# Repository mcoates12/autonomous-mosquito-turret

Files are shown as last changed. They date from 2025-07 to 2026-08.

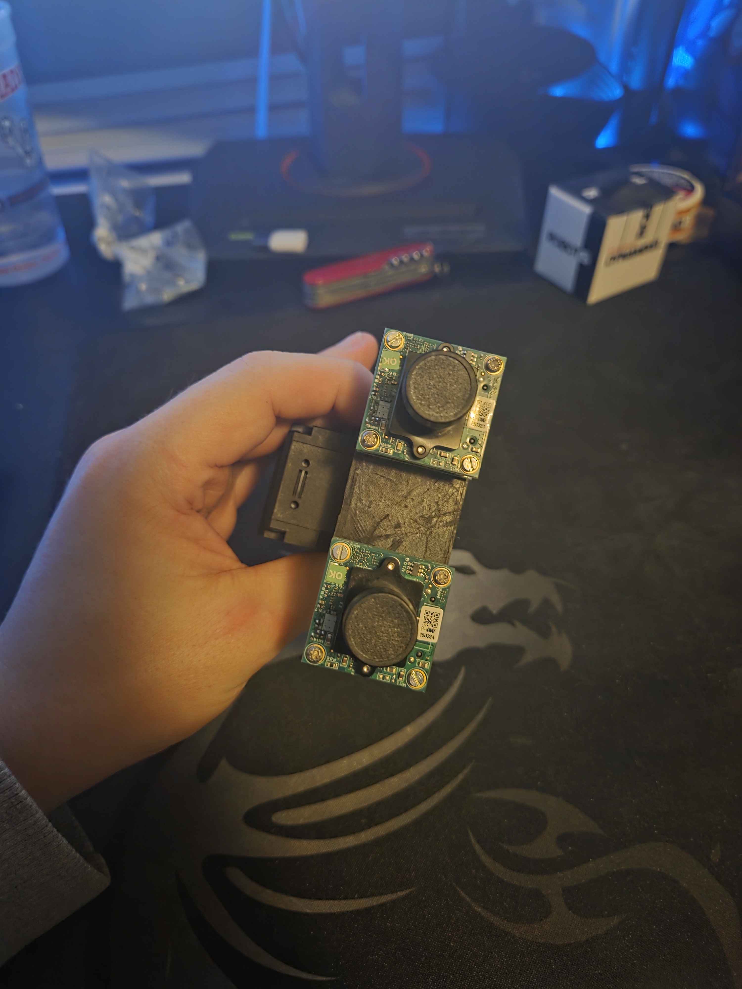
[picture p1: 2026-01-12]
images/turret3.jpg

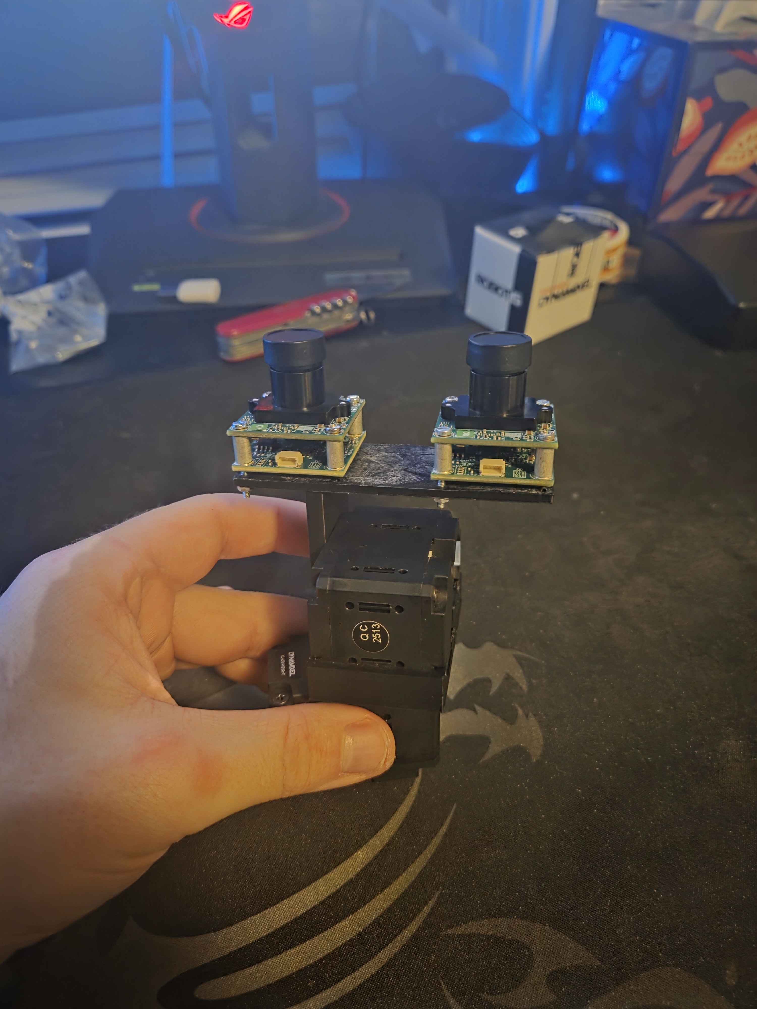
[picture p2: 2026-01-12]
images/turret1.jpg

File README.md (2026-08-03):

# Autonomous Mosquito-Killing Turret

A real-time, dual-camera turret system designed to detect, track, and eliminate mosquitoes using AI-based vision, stereo depth estimation, and precision servo control. Built solo from scratch as a self-funded engineering challenge and proof of capability.

---

## Objective

Create a fully autonomous turret capable of:
- Detecting flying mosquitoes in real-time up to 2 meters away
- Tracking targets using stereo vision and depth estimation
- Driving high-speed Dynamixel servos to follow targets
- Executing a "kill" action (via zap or simulated event)
- Implements real-time mosquito path prediction using a Kalman filter to estimate future positions and improve turret accuracy.

---

## System Overview

| Component | Description |
|---|---|
| Jetson Orin Nano | Real-time inference, image processing, control logic  |
| 2x AR0234 Cameras| Global shutter cameras for synchronized stereo input  |
| 16mm Lenses | Narrow FOV for long-range detection accuracy |
| Dynamixel XL430  | Precision pan/tilt control with speed + torque |
| YOLO | Object detection model trained on mosquito imagery |
| 3D Printed Parts | Custom mounts, housing, and brackets |

---

## Features (WIP)

- [x] Hardware purchased
- [x] Prototype brackets and mounts 3d printed
- [x] Dual-camera vision setup
- [x] Servo communication + movement test
- [x] Depth estimation from stereo input
- [ ] Path prediction via kalman filter
- [ ] Real-time AI inference
- [ ] Final turret housing designed
- [ ] Turret Housing 3d printed
- [ ] Multi-step kill logic (detection + motion confirm + depth range)
- [ ] Fail-safe & safety protocols
- [ ] Audible status beeps for states (idle, tracking, kill-ready)

---

## Project Structure

---

## Browser troubleshooting dashboard

The recommended troubleshooting interface runs on the Jetson without a Linux
desktop or VNC session. Camera capture, detection, and servo control stay on the
Jetson; the PC receives a reduced-rate diagnostic MJPEG preview and sends only
validated parameter changes.

On the Jetson:

```bash
cd ~/Documents/autonomous-mosquito-turret
git pull --ff-only origin main
python3 src/laser_follow_web.py
```

Tracking starts disabled. Keep the Jetson terminal open, and press `Ctrl+C` for
a clean shutdown and torque-off.

When using VS Code Remote SSH, open the **Ports** panel, choose **Forward a
Port**, enter `8080`, then open the forwarded address in the PC browser.

Alternatively, keep this command running in a Windows PowerShell window:

```powershell
ssh -N -L 8080:127.0.0.1:8080 myles@192.168.1.141
```

PowerShell showing no prompt or output means the tunnel is working. Open
<http://127.0.0.1:8080> in the PC browser. The dashboard automatically disables
tracking if its heartbeat disappears for five seconds.

For a trusted private LAN only, the dashboard can be exposed directly with
`python3 src/laser_follow_web.py --bind 0.0.0.0`, then opened at
`http://JETSON_IP:8080`. This mode has no authentication, so the SSH/VS Code
forward is preferred.

The diagnostic stream defaults to 10 FPS at 960 pixels wide and does not set
the camera capture rate. On a heavily loaded Jetson, reduce dashboard overhead
with `--preview-fps 5 --preview-width 640`.

During active tracking, reacquisition remains anchored to the last accepted
target. If the dot is lost, the turret holds instead of switching to a distant
red object. Press **Stop**, place the dot at the new location, and press
**Start** to deliberately clear that identity and perform a fresh full-frame
acquisition. The dashboard's `Reacquire radius` controls the allowed distance.

The outer motion loop uses independent pan and tilt proportional gains plus
filtered derivative damping. Damping is calculated from timestamped target
error, so it does not depend on camera or controller frame rate. It resets on
target loss, stale data, or tracking stop. The starting values are pan/tilt
gain `0.003`, pan damping `0.006`, tilt damping `0.003`, smoothing `35 ms`, and
maximum step `0.60 deg`. Raise damping gradually to reduce single-pass
overshoot; excessive damping can produce twitch or hesitation.

Servo goal commands remain at the selected controller rate (60 Hz by default),
while position/velocity feedback runs at 30 Hz and full health telemetry at
1 Hz. Hardware-error bytes are checked against the XL430's defined `0x3D` bit
mask; impossible reserved-bit values are retried and persistent invalid reads
still trigger the torque-off safety latch.

The runtime prefers the Jetson `nvv4l2camerasrc`/`nvvidconv` VIC conversion
path and automatically falls back to the portable software pipeline if it is
unavailable. In the preview overlay, `FPS` is the processed tracking rate and
`src` is the selected camera's independently measured delivery rate.

> 🔍 [Read the full project backstory → logs/project-intro.md](logs/project-intro.md)

## 👤 Author

**Myles**  
Junior Mechanical Engineering Student  
Self-taught builder | Defense-focused 

Feel free to fork, contribute, or reach out for questions.

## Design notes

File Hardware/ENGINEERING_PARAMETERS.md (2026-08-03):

# Turret Engineering Parameters

Last updated: 2026-08-02

This file records measured and modeled parameters used for controller sizing,
tracking development, and future calibration. Values marked preliminary must be
remeasured after the final lenses, wiring, fasteners, and accessory hardware are
installed.

## Camera system

- Camera count: 2
- Sensor: onsemi AR0234 global shutter
- Capture format: 1920 x 1200, UYVY
- Confirmed capture rate: 60 FPS
- Pixel size: 3 micrometers
- Lens holder: expected M12 x 0.5 S-mount; verify against the exact camera module
  before ordering replacements
- Current focus: manually adjusted by threading each lens in or out
- Final replacement lens focal length: not yet selected
- The README's 16 mm lens entry describes an intended configuration, not a
  verified final optical configuration

The stored camera calibration has approximately 1,105 pixel focal length. With
3 micrometer pixels, this implies that the lenses used for those images were
approximately 3.3 mm focal length. This estimate is approximate because focus,
distortion, and calibration quality affect the fitted intrinsics.

### Known V4L2 controls

- `/dev/video1` identifies Camera 1 (`ar0234 10-0042`) and reports
  1920 x 1200 UYVY capture at 60 FPS
- Exposure modes: full-frame automatic, manual, and ROI automatic
- Absolute exposure range: 1 to 10,000
- Gain range: 1 to 40
- Automatic and fixed white balance are supported
- Low-latency mode is supported
- Current software startup: automatic exposure and automatic white balance,
  gain 1, and low-latency mode enabled
- Manual tuning starts from exposure 100 (10 ms under standard V4L2 units) and
  fixed white balance 4600 when the operator enables those modes
- The GUI caps manual exposure at 160 (16 ms) to avoid silently reducing a
  nominal 60 FPS stream through excessive exposure time

## Stereo calibration

Historical calibration record:

- Captured stereo pairs: 22
- Usable stereo pairs: 21
- Checkerboard: 9 x 6 inner corners
- Measured square size: 18 mm
- Left reprojection RMS: 0.1703 pixels
- Right reprojection RMS: 0.1772 pixels
- Stereo reprojection RMS: 0.5314 pixels
- Reported corrected baseline: 0.0500 m

Important active-file mismatch:

- `src/stereo_calib/stereo_calibration_full.npz` currently embeds a 0.040 m
  square size and a 0.111211 m baseline.
- Scaling that baseline by 18/40 gives 0.050045 m, which agrees with the
  historical corrected result.
- The active file therefore has the old scale and must not be trusted for
  metric depth. It would report distances approximately 2.22 times too large.
- Exposure and brightness changes do not inherently invalidate geometric
  calibration, but lens focus changes, lens replacement, or camera movement do.
- Perform the final stereo calibration only after installing, focusing, and
  mechanically locking the final matched lenses.

## Servos and mechanical limits

- Servo model: Dynamixel XL430-W250
- Protocol: 2.0
- Operating mode: position control
- Serial device: `/dev/ttyUSB0`
- Baud rate: 1,000,000
- Pan servo ID: 1
- Tilt servo ID: 2
- Pan hardware range: 0 to 4095 ticks (approximately 0 to 359.91 degrees)
- Tilt hardware range: 0 to 2190 ticks (approximately 0 to 192.48 degrees)
- Temporary software tilt guard: 708 to 2190 ticks (approximately 62.23 to
  192.48 degrees)
- The controller refuses to arm if startup feedback is outside its effective
  software limits.

Known Dynamixel gain values from Wizard screenshots, for both servos:

- Velocity P Gain: 100
- Position I Gain: 0
- Feedforward 2nd Gain: 0

Still to record:

- Velocity I Gain
- Position D Gain
- Position P Gain
- Feedforward 1st Gain

## Preliminary tilt-axis properties

The modeled tilt payload includes both modeled camera/lens assemblies and the
moving tilt bracket.

- Moving mass: 0.05070 kg
- Weight under standard gravity: approximately 0.497 N
- COG relative to `CS_Tilt`:
  - X: -0.01722 m
  - Y: -0.00020 m
  - Z: 0.03919 m
- Tilt shaft is aligned with the `CS_Tilt` X-axis
- Perpendicular COG radius: 0.03919 m
- Moment of inertia about tilt shaft: 9.0293e-5 kg*m^2
- Maximum static gravity torque: approximately 0.01948 N*m

The tilt model does not yet include external fasteners, wiring/ribbon cables,
accessory hardware, or omitted rotating horn hardware. These values are a
modeled lower bound. Cable forces may contribute more position-dependent torque
than their mass suggests.

## Preliminary pan-axis properties

These properties are based on the current modeled upper assembly.

- Moving mass about pan axis: 0.11850 kg
- COG relative to `CS_Pan` in the upright/startup pose:
  - X along pan shaft: 0.03269 m
  - Y: 0.00168 m
  - Z: -0.00581 m
- Radial COG offset from pan shaft: approximately 0.00605 m
- Pan inertia in upright/startup pose: 6.54e-5 kg*m^2
- Estimated worst-case pan inertia over current tilt range: 1.69e-4 kg*m^2
- Conservative pan inertia for controller sizing: 1.7e-4 kg*m^2

Assuming the pan shaft is vertical, gravity does not create commanded torque
about the pan axis. Pan torque is dominated by angular acceleration, drivetrain
friction, cable resistance, and any base inclination.

## Current preliminary controller parameters

- Control update target: 60 Hz
- Dynamixel Profile Velocity starting value: 200
- Dynamixel Profile Acceleration starting value: 30
- Tracking smoothness is prioritized over the fastest possible acquisition,
  while retaining enough response to follow a moving target
- Red-dot detection is the current test source; the detector/controller seam is
  intentionally model-neutral for a later object detector

Desired maximum physical pan and tilt speeds have not yet been selected.

## Remaining measurements and validation

- Run the committed controller on the Jetson and collect
  `laser_follow_debug.log`.
- Record stationary, slow-sweep, fast-sweep, reversal, and irregular-motion
  tests when lighting permits.
- Establish the physical aim point in image coordinates rather than assuming
  the numerical image center.
- Measure camera/aiming-axis offsets from the pan and tilt axes.
- Record the missing Dynamixel gains.
- Select desired maximum pan and tilt speeds.
- Perform controlled 50, 100, 250, and 500 pixel step-response tests.
- Record acceptable overshoot and settling time, plus observed backlash,
  buzzing, oscillation, and axis coupling.
- Measure end-to-end camera-to-motion latency before tuning prediction or
  feedforward lead.
- Recalculate final mass, COG, and inertia after all hardware and cable routing
  are complete.

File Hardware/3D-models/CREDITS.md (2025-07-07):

# Credits

## Side Mount for XL430 Servo

**Model:** Dynamixel Mounting Plate  
**Author:** Dash Daring ([Printables profile](https://www.printables.com/@DashDaring_227093))  
**License:** [Creative Commons BY-NC 4.0](https://creativecommons.org/licenses/by-nc/4.0/)  
**Source:** [https://www.printables.com/model/924210-dynamixel-mounting-plate/files](https://www.printables.com/model/924210-dynamixel-mounting-plate/files)  
**Notes:** Modified to allow the mount to fit directly onto another servo horn.

---

## Dynamixel XL430-W250-T SolidWorks Files

**Model:** XL430-W250-T  
**Author:** Florian F  
**License:** Not specified on source page  
**Source:** [https://grabcad.com/library/dynamixel-xl430-w250-t-1](https://grabcad.com/library/dynamixel-xl430-w250-t-1)  
**Notes:** No modifications were made. Attribution included out of courtesy.

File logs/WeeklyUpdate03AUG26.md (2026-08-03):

# Project Update — Tracking and Control Overhaul

It has been a while since I seriously worked on this project, but over the last
few days I came back to it and made what is probably the biggest software jump
the turret has had so far.

The goal for this round of work was not to add the mosquito-detection model yet.
I still want to find an existing model trained on mosquitoes if possible instead
of immediately committing to building and labeling an entire dataset myself.
For now, I wanted to get the camera pipeline, red-dot detection, targeting,
servo control, safety behavior, and troubleshooting workflow as polished as I
could. The red laser dot is still acting as a stand-in target so I can work on
the motion system without mixing AI-model problems into controller problems.

At this point, the tracking is honestly close to perfect. There are still a few
small parameters I can min/max, but the turret went from laggy, jittery, and
occasionally locking onto random objects to tracking fast laser movement very
smoothly.

---

## The Original Performance Problem

The biggest problem when I started was rectification. As soon as I loaded the
GUI, the camera pipeline dropped to around **8 FPS**, even though both AR0234
cameras are capable of delivering **1920 × 1200 UYVY at 60 FPS**.

The debug timing made the bottleneck obvious:

- Camera capture: roughly **35–37 ms**
- Full-frame rectification: roughly **80.8 ms**
- Red-dot detection: roughly **18–19 ms**

The software was doing expensive stereo work in the main tracking path whether
it was needed or not. That meant the detector and controller were constantly
working from old frames, which made the entire turret feel delayed.

I reworked the pipeline so that:

- Each camera has a latest-frame capture thread instead of making the tracking
  loop wait on every frame.
- Old frames are dropped instead of building a backlog.
- Red-dot detection runs on the raw tracking-camera image.
- Full stereo rectification and disparity work happen only on scheduled depth
  updates.
- Depth processing runs in a separate worker and consumes only the newest
  request.
- Rectification maps use OpenCV's faster fixed-point representation.
- Preview rendering is demand-driven, so a future headless system does not pay
  for GUI work it is not using.

This removed full-frame rectification from the critical tracking path.

---

## Jetson Camera Acceleration

The next major improvement was the camera conversion pipeline. The Jetson was
spending too much time doing UYVY-to-BGR conversion in software, so I added an
NVIDIA VIC-accelerated GStreamer path using `nvv4l2camerasrc` and `nvvidconv`.
The software still has a portable conversion fallback if the accelerated path
cannot open.

There was an additional caps-negotiation problem that caused GStreamer critical
warnings and fallback behavior. I corrected the pipeline so the caps are fixed
properly before OpenCV receives the frames.

After these changes, the tracking pipeline went from roughly **8 FPS** to around
**55–60 FPS**. The browser preview can intentionally run slower to save network
and encoding overhead, but the actual camera capture, detection, and controller
continue running at full speed on the Jetson.

---

## Camera Exposure and Lighting

One of the early tests looked almost completely black. I originally thought
something was wrong with the camera, but the manual exposure settings were just
far too dark for the room.

The software now starts with:

- Automatic exposure enabled
- Automatic white balance enabled
- Gain set to **1**
- Low-latency camera mode enabled

Manual controls are still available when I need repeatable detector tests. The
starting manual exposure is **100**, which is approximately **10 ms** using the
standard V4L2 units. The GUI caps manual exposure at **160**, or approximately
**16 ms**, so a long exposure cannot silently force a nominal 60 FPS stream to
run slower.

Sunlight was still making the red dot difficult to detect. It turned out that
the laser pointer battery was also weak. Replacing the battery made a huge
difference and gave the detector a much cleaner target.

---

## Headless Browser Dashboard

The Qt GUI is only a troubleshooting tool. The final turret is supposed to run
headless, so I added a browser dashboard that runs directly from the Jetson.

The Jetson now handles:

- Camera capture
- Detection
- Stereo depth work
- Servo control
- Safety logic

My PC only receives a reduced-rate MJPEG troubleshooting preview and sends
validated parameter changes back to the Jetson. I can access it through VS
Code's SSH port forwarding or a normal SSH tunnel, so I no longer need to fight
with VNC, X11 forwarding, black screens, or Qt display errors.

The dashboard also has a heartbeat fail-safe. If the browser connection
disappears for five seconds, tracking is disabled.

No private IP address or network credentials are stored in the repository.

---

## Red-Dot Detector Improvements

The original red detector worked in ideal conditions, but it would either miss
the dot in bright lighting or lock onto things like the brown cardboard box at
the bottom of the camera image.

I added several layers of filtering:

- Brightness threshold
- Saturation threshold
- Minimum and maximum blob area
- Peak-brightness gate
- Local brightness-contrast gate
- Local red-contrast gate
- Hard area gate
- Image-edge exclusion

The detector now preserves tiny laser candidates instead of removing them with
an overly aggressive morphology pass. It also rejects broad reddish or brown
objects that do not have the small, bright, locally red appearance of the laser
dot.

Candidates near the image edge are ignored because partial blobs and bright
objects cut off by the frame were causing false locks.

The current detector values are:

- Brightness threshold: **80**
- Saturation threshold: **35**
- Minimum area: **1 pixel**
- Maximum area: **3000 pixels**
- Peak brightness gate: **140**
- Local contrast gate: **25**
- Local red-contrast gate: **12**
- Image-edge exclusion: **48 pixels**
- Hard area gate: **3000 pixels**

These are troubleshooting values for the red-dot detector, not permanent
mosquito-model parameters.

---

## Target Identity and Reacquisition

Another serious problem was target switching. If the dot moved quickly or
temporarily disappeared, the detector could jump to an unrelated red object and
then keep moving its search anchor toward that false target.

The detector now preserves the last confirmed target identity. During active
tracking, a new candidate must stay within the configured **300-pixel
reacquisition radius** of the last accepted target. Rejected outliers do not get
to move the anchor.

If the dot is lost, the turret holds its position instead of searching the
entire frame and choosing a random red object. Pressing **Stop** and then
**Start** intentionally clears the old identity and allows a fresh full-frame
acquisition.

This logic is detector-neutral, so the same target-observation interface can be
used by a future mosquito model.

---

## Servo Controller Rewrite

I separated servo control from the camera frame loop. The Dynamixel bus now has
its own fixed-rate controller thread that always consumes the newest target
error instead of sending commands whenever a camera frame happens to finish.

The controller now includes:

- Fixed-rate **60 Hz** goal commands
- Latest-target-only behavior
- Stale-target rejection
- Time-scaled movement that does not change with frame rate
- Safe startup without jumping to an old command
- Explicit torque-off behavior
- Dynamixel bus watchdog configuration
- Position, velocity, load, voltage, temperature, and hardware-error telemetry
- Thread-safe shutdown and fault latching

Position and velocity feedback now run at **30 Hz**, while full health telemetry
runs at **1 Hz**. Goal commands remain at 60 Hz. This reduces unnecessary bus
traffic because a servo feedback transaction was taking roughly **12–14 ms**
inside a **16.7 ms** controller period.

The 1 Hz health transaction already includes position and velocity, so the
software reuses that information instead of immediately performing another
feedback read.

---

## Servo Limits and Safety

The software reads the position limits stored in the servos instead of assuming
generic values.

Current limits:

- Pan ID 1: **0–4095 ticks** (approximately 0–359.91°)
- Tilt ID 2 hardware range: **0–2190 ticks** (approximately 0–192.48°)
- Temporary software tilt guard: **708–2190 ticks** (approximately
  62.23–192.48°)

The extra tilt minimum is a conservative mechanical restriction based on the
current assembly. I can change it later after more physical testing. The
controller refuses to arm if the startup feedback is outside the effective safe
range.

Tracking starts disabled, and confirmed controller faults torque the system off
and remain latched until I explicitly re-arm it.

---

## Dynamixel Communication Faults

While testing fast movement, the servo system occasionally shut itself off.
The first problem was an `Incorrect status packet` response during the hardware
status read. I added three bounded attempts with a short delay between them.
A persistent communication problem still shuts down and latches the controller.

Later, the log reported:

```text
pan=0xf3 tilt=0x13
```

Those values looked like hardware faults, but they were impossible XL430 error
bytes. The only valid hardware-error bits combine into mask `0x3D`; bits 1, 6,
and 7 are reserved and must always be zero. Both reported values contained
reserved bits.

The software now validates hardware-error bytes against `0x3D`:

- Impossible reserved-bit values are retried.
- Three persistent invalid values become a latched communication fault.
- Valid nonzero hardware-error bits remain immediately fatal.
- The controller never automatically re-enables torque after a confirmed
  failure.

This keeps the safety behavior while preventing one corrupted telemetry byte
from pretending to be two simultaneous servo failures.

---

## Tracking and Damping

The first tracking controller was essentially proportional-only. It moved
toward the current pixel error, but fast laser movement caused oscillation and
single-pass overshoot.

I first tuned the basic values to:

- Pan gain: **0.003 degrees/pixel**
- Tilt gain: **0.003 degrees/pixel**
- Maximum step: **0.60°** at the 60 Hz reference rate
- Target smoothing: **35 ms**
- Deadband: **25 pixels**
- Profile velocity: **200**
- Profile acceleration: **30**

Reducing the pan gain removed the repeated side-to-side oscillation. Reducing
the smoothing delay and maximum step reduced the remaining overshoot, but a
fast pass could still cross the target once and correct back.

I then added independent filtered derivative damping for both axes:

- Pan damping: **0.006**
- Tilt damping: **0.003**

The damping uses the timestamped rate of change of pixel error. When the error
is closing quickly, it begins braking before the turret crosses the target. It
is filtered to reduce detector noise and resets whenever the target is lost,
becomes stale, or tracking is stopped.

This is not a full traditional PID loop, and I do not currently plan to add an
integral term. The controller already accumulates position commands, and an
additional integral term could create windup. The current proportional plus
derivative behavior is smooth, responsive, and very close to where I want it.

---

## Mechanical Parameters Recorded

I rebuilt the assembly in SolidWorks so I could estimate the moving mass,
center of gravity, and moment of inertia for each axis.

### Tilt axis

- Moving mass: **0.05070 kg**
- Weight: approximately **0.497 N**
- Perpendicular COG radius: **0.03919 m**
- Moment of inertia: **9.0293e-5 kg·m²**
- Maximum estimated gravity torque: approximately **0.01948 N·m**

This model includes the two camera/lens assemblies and moving tilt bracket. It
does not yet include all fasteners, wiring, ribbon cables, laser hardware, or
omitted rotating horn hardware.

### Pan axis

- Moving mass: **0.11850 kg**
- Radial COG offset in the upright pose: approximately **6.05 mm**
- Upright moment of inertia: **6.54e-5 kg·m²**
- Estimated worst-case inertia over the tilt range: **1.69e-4 kg·m²**
- Conservative controller-design value: **1.7e-4 kg·m²**

These values give me a much better starting point for future controller sizing
and acceleration limits than guessing from the servo specifications.

---

## Testing and Code Quality

The tracking code is now split into reusable pieces instead of being one giant
GUI-dependent loop. Camera pipelines, target observations, filtering, depth,
servo control, dashboard validation, and motion math can be tested separately.

The repository currently has **47 passing automated tests** covering areas such
as:

- Camera pipeline selection and fallback
- Frame-rate-independent filtering and motion
- Position conversion and safe limits
- Dashboard input validation and heartbeat behavior
- Stale-target handling
- Target identity and reacquisition radius
- Proportional/derivative damping math
- Servo torque-off and fault latching
- Communication retries
- Hardware-status mask validation
- Decoupled command, feedback, and health rates

This is especially important because the final detector may change from a laser
heuristic to YOLO or another model, but the controller and safety behavior
should not have to be rewritten.

---

## Current Status and Next Steps

The turret currently tracks the laser dot at approximately **55–60 FPS** and
moves smoothly without the repeated oscillation I was seeing before. Fast
movement can still use some very small tuning changes, but I would describe the
current behavior as near perfect for this stage of the project.

My next steps are:

1. Make small pan and tilt damping adjustments and record the final values.
2. Record controlled stationary, slow-sweep, fast-sweep, reversal, and
   irregular-motion tests.
3. Measure overshoot, settling time, end-to-end latency, backlash, and any axis
   coupling instead of judging everything only by eye.
4. Establish the physical aiming point in camera coordinates rather than
   permanently assuming the numerical center of the image.
5. Find and integrate a mosquito-detection model behind the existing
   detector-neutral target interface.
6. Add velocity prediction/feedforward after the measured controller baseline
   is complete. A Kalman filter may eventually provide the state estimate, but
   it is not the feedforward loop by itself.
7. Keep the troubleshooting dashboard for development while moving the final
   system toward fully headless operation.

This round of work was a lot of debugging, but the result finally feels like a
real tracking platform instead of a camera script connected to two servos. The
AI model is still ahead, but the foundation it will plug into is dramatically
better than it was before.

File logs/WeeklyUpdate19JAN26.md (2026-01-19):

## Project Update

I was so excited with the progress I made that I logged off and decided to watch a movie and relax. It’s honestly kind of amazing seeing how far this turret has come already, and I’m even more excited to keep pushing forward.

---

## Camera Calibration Progress

E-con finally emailed me back, and I wrote a short OpenCV script to take photos for camera calibration. In total, **22 photos** were taken, with **21 usable** according to OpenCV.

Initially, I tried using my cell phone, but it has a privacy screen that blurs the image edges at an angle, which made it unusable. Since I don’t have access to a printer or a Sharpie, I switched to using my tablet instead.

The first attempt with the tablet was a no-go due to camera lighting settings. After adjusting exposure and brightness on both the cameras and the tablet, I finally got calibration results that (from what I’ve read) are considered quite good:

OpenCV camera errors
Left reprojection error: 0.1703
Right reprojection error: 0.1772
Stereo reprojection error: 0.5314
Baseline (meters): 0.0500
Baseline (centimeters): 5.00

Originally, I generated the checkerboard online with square sizes of **40 mm × 40 mm**, which resulted in an estimated baseline of ~11 cm. That seemed wrong given how close the cameras actually are.

After some checking, thinking, and double-checking, I realized the tablet was **shrinking the image** to fit its aspect ratio. I measured the squares manually with a ruler and found they were actually **18 mm × 18 mm**. After updating that value in the calibration script, OpenCV correctly calculated the camera baseline.

I also added:
- Image rectification (to keep objects aligned on the same axis)
- Centroid detection

---

## Servo Movement

Next, I started working on servo movement. I wrote a small script using the **Dynamixel SDK** and got basic control working.

Unfortunately, I don’t yet have a proper baseplate for the turret, and it’s pretty top-heavy. It kept falling over, so I improvised:
- Broke off a plastic clothes hanger
- Secured it together with electrical tape
- Taped one of my older pan mounts onto it so the servo could sit inside

Not pretty — but functional for now.

---

## Object Detection & Laser Tracking

Once the servos were responding correctly, I started working on actual object-tracking logic. I created `laser_track.py` and decided to test it using a laser pointer on the wall.

Since I have a cat (and cats love laser pointers), it felt like a perfect test case.

Right now, the script:
- Detects the **hue** of the laser
- Initially only detected the laser within ~6 inches of the camera
- Improved detection range by tuning `v_thresh` and `s_thresh`

Lighting was still somewhat challenging due to sunlight coming through my window, but it worked well enough. Watching the turret move and track the laser for the first time was *incredibly* exciting.

After recording a few videos and posting on Facebook and Instagram, I noticed the movement felt slow. I started tuning motion parameters and landed on:

deg_per_px: 0.006 (pan & tilt)
velocity profile: 200
steps: 3
deadband_px: 10

The turret is now significantly faster, but it feels **jittery** — like it wants to move faster but something is holding it back. I expect most of this will be resolved once I integrate proper **PID control**.

---

## Next Steps

Planned work moving forward:

1. Implement **PID controls**
2. Add **prediction logic** using an **Unscented Kalman Filter**
3. Move into AI vision:
   - **Option A:** Find an existing mosquito-detection model
   - **Option B:** Train my own model

I don’t expect GPU limitations to be an issue — I’m running an **RTX 5090**, so local training should be fine. The bigger challenges will be:
- Finding or building a dataset
- Labeling bounding boxes
- Training the model properly

I also plan to include images of:
- Humans
- Cats
- Dogs
- Other insects

This will allow the model to differentiate targets and enforce safety logic so the turret **does not engage** near people or pets.

Additional planned features:
- Safety protocols
- Laser integration
- Audio cues (beeper tones) for:
  - Scanning
  - Lock-on
  - Firing

---

## Project Status & Reflections

It’s hard to say exactly how far along I am, but I’d estimate I’m around **halfway**, maybe a bit more.

This milestone has been one of the most exciting things I’ve ever experienced. Watching something go from a random idea to a system that can **see**, **track**, and **move** is easily one of the top five most rewarding things I’ve ever done.

There are still hardware challenges ahead — especially with the **CSI camera cables**, which are far too short to allow full turret motion. I’m trying to avoid buying new cameras if possible. I may experiment with:
- Short CSI cables → CSI-to-Ethernet converters → Ethernet → back to CSI

I’ve read that longer CSI runs can introduce lag or signal issues, so this will require experimentation.

---

## Closing

Thanks to everyone who’s been following along. I genuinely can’t stress enough how exciting this project has been for me.

See you all next week 🚀

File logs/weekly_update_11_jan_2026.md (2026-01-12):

# Weekly Update – 11 Jan 2026

Progress is going great! I have finally built the tilt mount correctly. Admittedly, it took three additional iterations before I got it right. Along the way, I learned that M2, M2.5, and M3 screws typically use **Japanese Industrial Standard (JIS)** drivers rather than standard Phillips heads, which has significantly improved assembly.

Earlier this week, I spent a day running around trying to find JIS drivers and other necessary tools. I eventually found a large driver set that included JIS bits, picked up wire cutters, and bought additional screws. I then had to make a few trips back to ACE Hardware to find the correct screw length for the cameras. I ultimately settled on **M2×20 screws** and successfully mounted both cameras.

I downloaded **Dynamixel Wizard 2.0** and set up power distribution through the power hub so the servos were properly powered. Using the Wizard, I configured the servos and set the tilt bounds to **62.23° – 191.78°**, ensuring the mount does not collide with the servo or other parts of the system.

Next, I flashed **JetPack 6.2** onto my Jetson Orin Nano and installed a **2 TB M.2 SSD**. After completing the setup, I attempted to install the camera software from the E‑consystems website. Unfortunately, they only provided **L4T version 36.4.0**, while my system is running **36.4.7**. As a result, I’ve been unable to install the camera drivers, QtCAM, or OpenCV. I emailed E‑consystems yesterday requesting the updated drivers and associated files and am currently waiting for a response.

At the moment, progress is somewhat dependent on E‑consystems, so hopefully they note reply soon. In the meantime, I can begin working on basic servo‑movement logic and decide on an object‑detection model. I’m currently leaning toward **YOLOv11**, but I plan to do more research before making a final decision.

Hope everyone has a great week! I’ll be back next week with another progress update. School starts next week as well, but I’ll be doing my best to maintain momentum and keep pushing this project forward.

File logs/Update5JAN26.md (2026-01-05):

Update (Very Late)

I finally printed the tilt mount for the turret. This took around five reprints, with each print taking roughly 5 hours, before I was able to get the servo horn to fit properly into the holes and sit flush with the mount. 
The main issue was that the holes kept warping, since that section of the mount was being printed vertically.

Yesterday, I went to Micro Center and picked up a variety of wires, switches, and related components so I can properly distribute power and handle sensor logic.

Today, I realized that I overshot the dimensions for the strip that the cameras screw into. At this point, I’m deciding whether to cut that section off or just reprint the part entirely.

Once that’s resolved, I’ll move on to the electrical work, followed by the coding phase to get the system moving. After that, I’ll begin camera calibration, and then continue iterating from there.

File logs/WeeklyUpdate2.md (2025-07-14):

# Weekly Update

It looks like I lied in the last weekly update. I ended up spending the first half of the week relaxing and the last half outdoors hanging out with friends. So unfortunately, no progress has been made so far.

I wanted to at least make the mounting bracket for the tilt servo, which I'm designing in SolidWorks as we speak. I should be finished with this either by tonight or tomorrow. This week will be low in productivity as well due to my upcoming Differential Equations and Thermodynamics exams.

After Thursday, I should start turning on all the equipment and updating everything. Then we’ll move on to actually getting the parts moving.

I also updated the first bracket one more time. I couldn’t fit the M2 screws through the 0.8 mm hole and realized the actual radius for that hole should be around 1 mm instead of 0.8 mm. I also cross-threaded one of the holes in the servo horn (whoops). I thought that a bigger screw I had was actually the same size as the M2 screw, but I found out very quickly that wasn't the case—haha.

Luckily, I have another horn, and for the final product, I’ll be replacing the plastic horn that came with it with the aluminum one I bought separately.

I guess that’s what I get for putting black screws on a black mousepad and trying to see the difference in sizes off of that. **Note to self:** set the screws on a white piece of paper or something that isn’t the exact same color as the screws themselves.

That should be it for this weekly update. Hopefully, next week’s should be a little more exciting.

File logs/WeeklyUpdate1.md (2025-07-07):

# Weekly Project Update – Week 1

This week’s update will be shorter than most. I’m taking two summer classes and had two exams this week, so most of my time this week went into studying, recovering from an illness, and the holiday. Still, I’m happy with the progress I made over the last few days.

I bought a SolidWorks 2025 student license a few months ago, and a buddy of mine let me borrow his Ender-3 Pro printer. I spent most of the Friday, Saturday, and today experimenting with printing and learning how the software and hardware work together.

---

## Mount Design and Modifications

I began by searching for different mounts I could 3D print and prototype with to accelerate my turret design process. Eventually, I stumbled upon a side-mount bracket that I’m currently using/modifying for my own specific use case ([see hardware/3d-models/credits.md for source info](./hardware/3d-models/credits.md)).

I printed off the original bracket and it fit perfectly on my XL430-W250-T servo—such a great match.

I started creating the platform that would attach to my pan servo horn so I connect both the pan and tilt servo by those brackets. I created the `PanMount.SLDPRT` file (in `hardware/3d-models`) using SolidWorks, which was a great learning experience. Rather than keeping an unnecessary part,

I thought: *"Why not just modify the original instead?"*

I imported the actual XL430 SolidWorks file so I could get accurate measurements of the screw holes for the horn and distances between each hole. I ended up modifying the bracket five times.

---

## Iterative Prints and Challenges

The first modification is saved as `dynamixel_mounting_plate_v102.stl`. When I printed it, I noticed the screws wouldn’t fit due to the bracket’s thickness (~5mm). I decided to add indents to the bracket so the screw heads could sit flush and the servo would still be able to fit.

This led to `mountfinal.stl`, which has ~0.8mm diameter holes with indents around 1mm deep. Unfortunately, the screw heads didn’t seat properly. I increased the radius in `mountfinalV2`, but the indents weren’t deep enough and the bracket printed messily.

Eventually, I adjusted the depth to ~3.5mm and the radius to ~2mm, resulting in a clean and well-fitting part: `finalmountV3.stl`. But there was another issue. The middle of the servo horn is where the screw is that attaches the horn to the actual servo and it sits at a 2mm height above where the actual screws are located. Which was something I didn't even think about when modifiying the original bracket.

---

## Slicer Settings and Printing Details

I’m currently printing with:
- Wall thickness: 1 mm  
- Wall line count: 3  
- Top/bottom layers: 6  
- Infill: 50%  
- Ironing: Enabled (top only)  
- Ironing flow: 20%  
- Print temp: 210°C (PLA+)  
- Speed: 30 mm/s depending on pass  
- Layer height: 0.2 mm  
- Supports: None  
- Slicer: Ultimaker Cura  

---

## Bracket Update and Next Steps

To avoid modifying the mount further and waiting another 3 hours for it to print, I looked around at the few hardware stores that are open on a Sunday to see if there was any longer m2.5 screws I could buy. Unfortunately, none of the nearby hardware stores that were open carried M2.5 screws, 

so I designed `finalmountV4.stl`, which uses a 2mm indent to better accommodate the raised screw head in the center of the horn.

so I’m waiting another 3 hours for this thing to finish printing.

This version allows the bracket and horn to sit flush while also providing holes for both the bracket and servo screws.

Next, I’m planning to create a **C-style tilt mount** for the second servo, ensuring enough spacing and proper alignment with the pan bracket. This should allow for synchronized movement.

---

## Looking Ahead

Next week, I’ll be:
- Finishing the bracket for the **tilt servo**
- Testing **servo movement**
- Installing cameras
- Starting work on **YOLOv8 model training**
- Learning **OpenCV** and depth estimation with stereo vision
- Beginning to write modular **Python code** for servo/camera integration

This week’s quote, as I begin this journey:

> *"A journey of a thousand miles begins with a single step."* — Lao Tzu

---

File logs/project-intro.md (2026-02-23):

# Project Log 1 – Autonomous Mosquito-Killing Turret

## Why I’m Doing This

By the end of my sophomore year in the BSME program, I wanted to start getting experience. Summer internships were off the table due to enrollment in summer classes, so I applied to the on-campus research program.

After months of emails, reminder follow-ups, and camping outside professors’ offices — I finally got the interview.

It lasted about an hour. Then they told me I wasn’t getting the position due to a lack of experience.

To get this experience I decided to build a self-funded, AI-powered turret that tracks and eliminates mosquitoes in real time.

My goal Isn’t just to kill bugs — it is to prove that I can design, build, and document a complete system from scratch. One that combines mechanical design, computer vision, embedded hardware, and AI.

---

## Final Words

Thank you to whoever stumbles across this and decides to read and follow along as I finish the project. I'm very open to critiques or general advice from more experienced folks. I'm new to GitHub and still learning the ropes.

If this repo starts seeing traffic, maybe I’ll toss in an email.  
Again, thanks for reading.

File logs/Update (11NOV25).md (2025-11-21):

## Project Status Update

Hey everyone!

I just wanted to let you all know that the project is **still actively ongoing**.

Between the end of the summer semester and the start of this one, things have been extremely busy. A lot of my time has been taken up by **schoolwork** and **searching for summer internships**, which slowed down development more than I anticipated.

I’m planning to resume work on the project **around finals**, once my schedule finally opens up again.

Thank you all so much for your patience — I’m excited to get back into this soon!

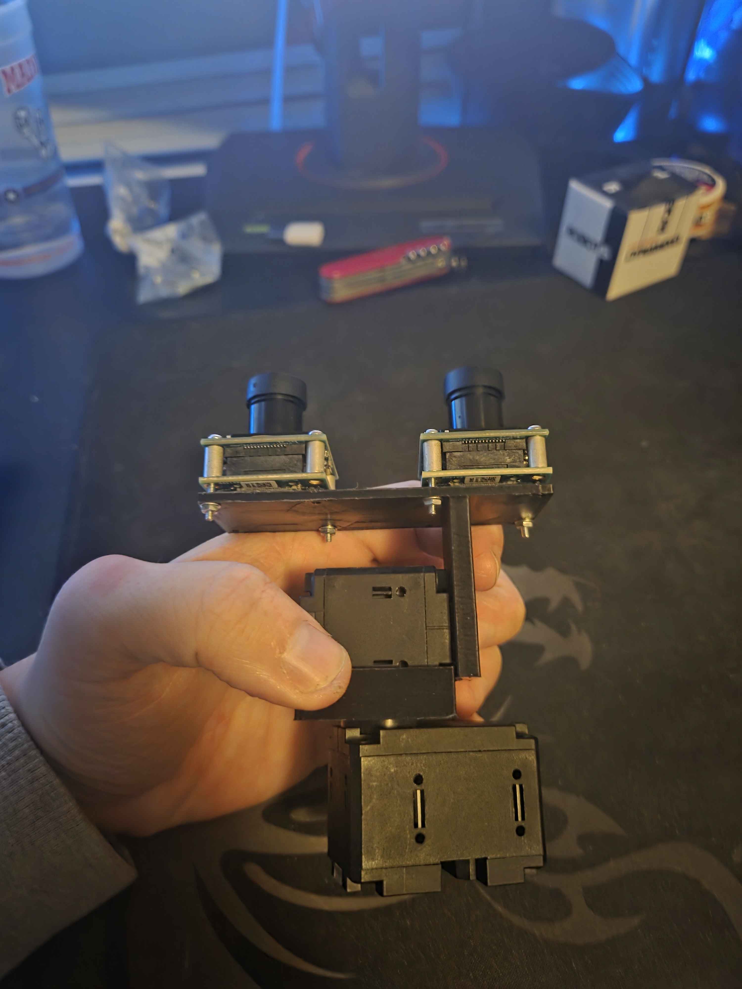
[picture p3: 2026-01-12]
images/turret2.jpg

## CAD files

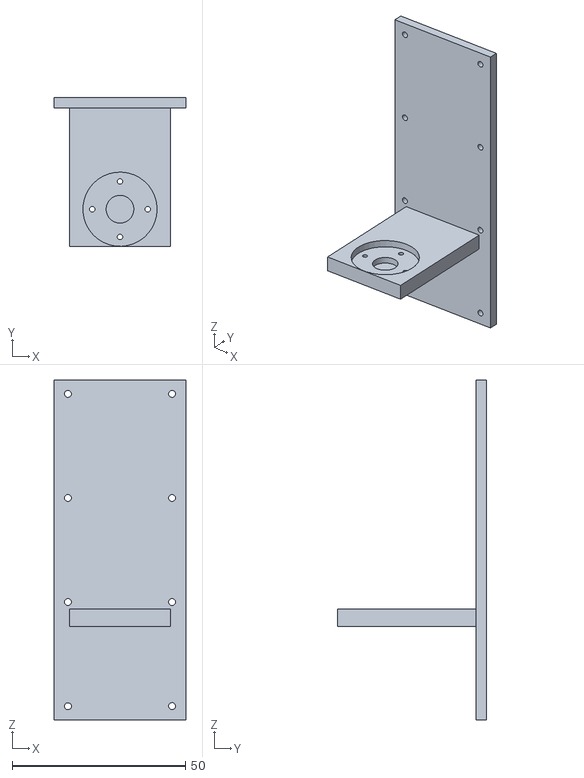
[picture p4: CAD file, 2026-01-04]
Hardware/3D-models/tilt mount V4.STL
38.0 x 43.0 x 98.0

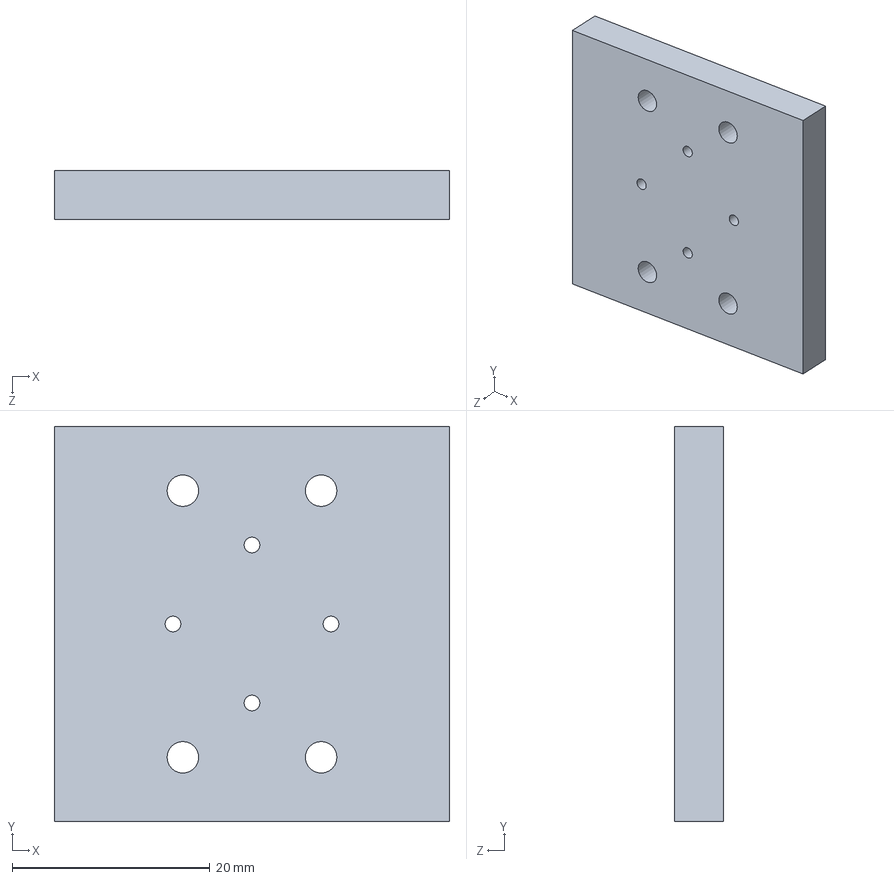
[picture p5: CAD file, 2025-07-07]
Hardware/3D-models/PanMount.SLDPRT
40.0 x 40.0 x 5.00 mm

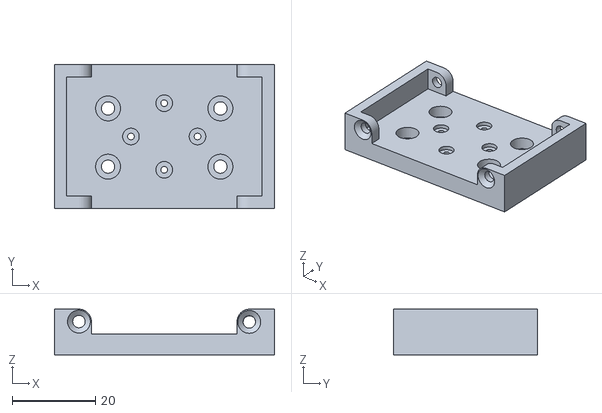
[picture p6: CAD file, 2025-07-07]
Hardware/3D-models/mountfinalV2.STL
52.9 x 34.5 x 11.0

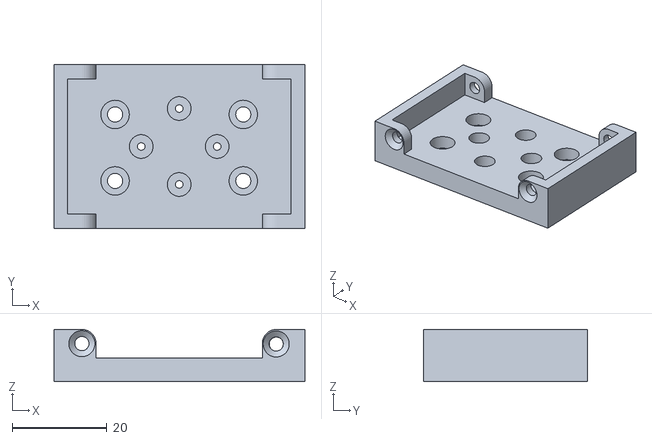
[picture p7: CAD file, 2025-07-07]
Hardware/3D-models/finalmountV4.STL
52.9 x 34.5 x 11.0

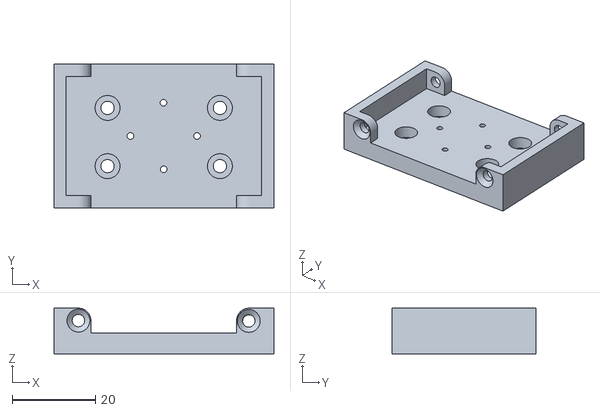
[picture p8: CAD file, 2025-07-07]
Hardware/3D-models/dynamixel_mounting_plate v102.STL
52.9 x 34.5 x 11.0

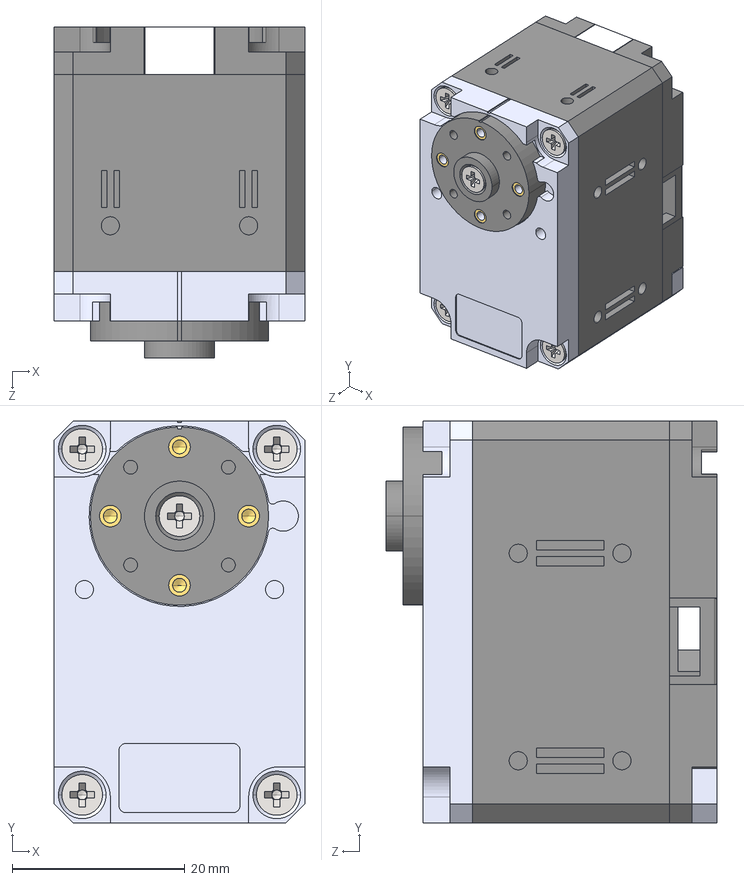
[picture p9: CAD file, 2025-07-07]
Hardware/3D-models/XL430_W250_T.STEP
29.0 x 46.5 x 38.3 mm
Part1^XL430_W250_T
Part2^XL430_W250_T
Part3^XL430_W250_T
Part4^XL430_W250_T
countersunk flat head cross recess screw_din_DIN EN ISO 7046-1 - M2.5 x 10 - Z - 10N x 9
Part5^XL430_W250_T
Part6^XL430_W250_T

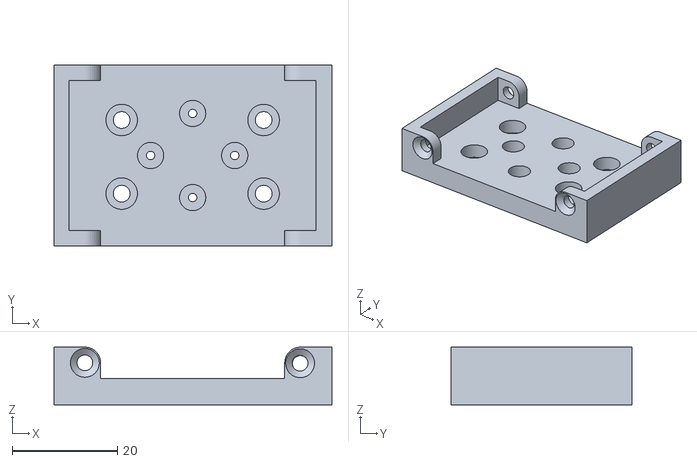
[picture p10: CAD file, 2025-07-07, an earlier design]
Hardware/3D-models/finalmountV3.STL
52.9 x 34.5 x 11.0

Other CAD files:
Hardware/3D-models/mountfinal.STL
Hardware/3D-models/dynamixel_mounting_plate v101.SLDPRT
Hardware/3D-models/tilt mountV1.STL
Hardware/3D-models/tilt mount V3.STL
Hardware/3D-models/tilt mount V2.STL

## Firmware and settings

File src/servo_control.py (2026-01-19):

#!/usr/bin/env python3
"""
Dynamixel XL430 (Protocol 2.0) pan/tilt control via U2D2 (TTL).

Features:
- Soft limits (tilt bounds prefilled)
- Degrees -> ticks conversion (0-360 deg => 0-4095)
- Torque enable/disable
- Operating mode set to Position Control
- Profile velocity control
- Commands: center, goto, step, sweep, status

Wiring:
- U2D2 USB to Jetson
- U2D2 TTL to Dynamixel chain + external power to servos (NOT from USB)

Author: ChatGPT
"""

import argparse
import math
import signal
import sys
import time
from dataclasses import dataclass

from dynamixel_sdk import PortHandler, PacketHandler, GroupSyncWrite, GroupSyncRead  # type: ignore

# -----------------------------
# XL430 Control Table (Protocol 2.0)
# -----------------------------
ADDR_OPERATING_MODE   = 11   # 1 byte
ADDR_TORQUE_ENABLE    = 64   # 1 byte
ADDR_PROFILE_VELOCITY = 112  # 4 bytes (profile velocity, used in position mode)
ADDR_GOAL_POSITION    = 116  # 4 bytes
ADDR_PRESENT_POSITION = 132  # 4 bytes

LEN_OPERATING_MODE   = 1
LEN_TORQUE_ENABLE    = 1
LEN_PROFILE_VELOCITY = 4
LEN_GOAL_POSITION    = 4
LEN_PRESENT_POSITION = 4

OPERATING_MODE_POSITION = 3  # Position Control Mode

TORQUE_ON  = 1
TORQUE_OFF = 0

# XL430 resolution: 0..4095 ticks for 0..360 degrees
TICKS_PER_REV = 4096.0
DEG_PER_TICK = 360.0 / TICKS_PER_REV


# -----------------------------
# Configuration (edit these)
# -----------------------------
@dataclass
class ServoConfig:
    servo_id: int
    name: str

    # Soft limits in DEGREES (logical, after applying invert/offset)
    min_deg: float
    max_deg: float

    # Home position in degrees (logical)
    home_deg: float

    # Optional: invert direction if your servo rotates opposite your desired sign
    invert: bool = False

    # Optional: offset in degrees (logical 0deg maps to physical position)
    # Example: if "0 deg" in your logic corresponds to servo sitting at physical 180 deg, set offset_deg=180
    offset_deg: float = 0.0


@dataclass
class TurretConfig:
    port: str = "/dev/ttyUSB0"
    baud: int = 1000000  # common default; change if you set different in Dynamixel Wizard
    protocol: float = 2.0

    # Limit rate of change to prevent whipping around
    max_step_deg_per_cmd: float = 15.0

    # Default profile velocity (0 = max, but don't do that). This value is in Dynamixel units.
    # Typical safe starting points: 50–200. Tune later.
    profile_velocity: int = 120

    # Servos
    pan: ServoConfig = ServoConfig(
        servo_id=1,
        name="pan",
        min_deg=0.0,
        max_deg=360.0,
        home_deg=180.0,
        invert=False,
        offset_deg=0.0,
    )

    tilt: ServoConfig = ServoConfig(
        servo_id=2,
        name="tilt",
        # Using YOUR safe tilt bounds:
        min_deg=62.23,
        max_deg=191.78,
        home_deg=120.0,
        invert=False,
        offset_deg=0.0,
    )


# -----------------------------
# Helpers
# -----------------------------
def clamp(x: float, lo: float, hi: float) -> float:
    return max(lo, min(hi, x))


def wrap_deg_0_360(deg: float) -> float:
    # keep in [0, 360)
    d = deg % 360.0
    if d < 0:
        d += 360.0
    return d


def int_to_little_endian_bytes(value: int, length: int) -> bytes:
    return int(value).to_bytes(length, byteorder="little", signed=False)


# -----------------------------
# Dynamixel Controller
# -----------------------------
class DynamixelTurret:
    def __init__(self, cfg: TurretConfig):
        self.cfg = cfg
        self.port_handler = PortHandler(cfg.port)
        self.packet_handler = PacketHandler(cfg.protocol)

        self.sync_write_goal = GroupSyncWrite(
            self.port_handler, self.packet_handler, ADDR_GOAL_POSITION, LEN_GOAL_POSITION
        )
        self.sync_read_present = GroupSyncRead(
            self.port_handler, self.packet_handler, ADDR_PRESENT_POSITION, LEN_PRESENT_POSITION
        )

        self._torque_enabled = False
        self._last_cmd_deg = {
            cfg.pan.name: None,
            cfg.tilt.name: None,
        }

    def open(self) -> None:
        if not self.port_handler.openPort():
            raise RuntimeError(f"Failed to open port {self.cfg.port}")
        if not self.port_handler.setBaudRate(self.cfg.baud):
            raise RuntimeError(f"Failed to set baudrate {self.cfg.baud} on {self.cfg.port}")

        # Register servos for sync read
        for s in (self.cfg.pan, self.cfg.tilt):
            ok = self.sync_read_present.addParam(s.servo_id)
            if not ok:
                raise RuntimeError(f"Failed to add servo {s.servo_id} to sync read")

    def close(self) -> None:
        try:
            self.torque_off_all()
        except Exception:
            pass
        try:
            self.port_handler.closePort()
        except Exception:
            pass

    # ---------- Low-level read/write ----------
    def write1(self, servo_id: int, addr: int, value: int) -> None:
        dxl_comm_result, dxl_error = self.packet_handler.write1ByteTxRx(
            self.port_handler, servo_id, addr, value
        )
        self._check_comm(servo_id, dxl_comm_result, dxl_error, f"write1 addr={addr} val={value}")

    def write4(self, servo_id: int, addr: int, value: int) -> None:
        dxl_comm_result, dxl_error = self.packet_handler.write4ByteTxRx(
            self.port_handler, servo_id, addr, value
        )
        self._check_comm(servo_id, dxl_comm_result, dxl_error, f"write4 addr={addr} val={value}")

    def read4(self, servo_id: int, addr: int) -> int:
        value, dxl_comm_result, dxl_error = self.packet_handler.read4ByteTxRx(
            self.port_handler, servo_id, addr
        )
        self._check_comm(servo_id, dxl_comm_result, dxl_error, f"read4 addr={addr}")
        return int(value)

    def _check_comm(self, servo_id: int, comm_result: int, dxl_error: int, what: str) -> None:
        if comm_result != 0:
            msg = self.packet_handler.getTxRxResult(comm_result)
            raise RuntimeError(f"[ID:{servo_id}] {what} COMM FAIL: {msg}")
        if dxl_error != 0:
            msg = self.packet_handler.getRxPacketError(dxl_error)
            raise RuntimeError(f"[ID:{servo_id}] {what} DXL ERROR: {msg}")

    # ---------- Setup ----------
    def ping(self) -> None:
        for s in (self.cfg.pan, self.cfg.tilt):
            model, comm, err = self.packet_handler.ping(self.port_handler, s.servo_id)
            self._check_comm(s.servo_id, comm, err, "ping")
            print(f"[OK] {s.name} ID={s.servo_id} model_number={model}")

    def set_position_mode_all(self) -> None:
        # Must disable torque to change operating mode
        self.torque_off_all()
        for s in (self.cfg.pan, self.cfg.tilt):
            self.write1(s.servo_id, ADDR_OPERATING_MODE, OPERATING_MODE_POSITION)
        print("[OK] Operating mode set to POSITION for both servos")

    def set_profile_velocity_all(self, profile_vel: int) -> None:
        # profile velocity can be written with torque on/off; safer with torque off initially
        for s in (self.cfg.pan, self.cfg.tilt):
            self.write4(s.servo_id, ADDR_PROFILE_VELOCITY, int(profile_vel))
        print(f"[OK] Profile velocity set to {profile_vel} (both)")

    def torque_on_all(self) -> None:
        for s in (self.cfg.pan, self.cfg.tilt):
            self.write1(s.servo_id, ADDR_TORQUE_ENABLE, TORQUE_ON)
        self._torque_enabled = True
        print("[OK] Torque ON (both)")

    def torque_off_all(self) -> None:
        for s in (self.cfg.pan, self.cfg.tilt):
            try:
                self.write1(s.servo_id, ADDR_TORQUE_ENABLE, TORQUE_OFF)
            except Exception:
                # if one servo isn't reachable, don't block shutdown
                pass
        self._torque_enabled = False
        print("[OK] Torque OFF (both)")

    # ---------- Conversions ----------
    def deg_to_ticks(self, servo: ServoConfig, deg_logical: float) -> int:
        # apply clamp in logical space first
        deg_logical = clamp(deg_logical, servo.min_deg, servo.max_deg)

        # apply rate limit (per-servo)
        last = self._last_cmd_deg.get(servo.name)
        if last is not None:
            max_step = self.cfg.max_step_deg_per_cmd
            deg_logical = clamp(deg_logical, last - max_step, last + max_step)

        # apply invert + offset mapping to physical deg (0..360 domain)
        d = deg_logical
        if servo.invert:
            # invert around 0 in logical space; you can change this behavior later if needed
            d = -d
        d = d + servo.offset_deg
        d = wrap_deg_0_360(d)

        ticks = int(round(d / DEG_PER_TICK)) % int(TICKS_PER_REV)
        self._last_cmd_deg[servo.name] = deg_logical
        return ticks

    def ticks_to_deg_physical(self, ticks: int) -> float:
        ticks = ticks % int(TICKS_PER_REV)
        return ticks * DEG_PER_TICK

    # ---------- Motion Commands ----------
    def set_pan_tilt_deg(self, pan_deg: float, tilt_deg: float) -> None:
        pan_ticks = self.deg_to_ticks(self.cfg.pan, pan_deg)
        tilt_ticks = self.deg_to_ticks(self.cfg.tilt, tilt_deg)

        # Build sync write packet
        self.sync_write_goal.clearParam()
        ok1 = self.sync_write_goal.addParam(self.cfg.pan.servo_id, int_to_little_endian_bytes(pan_ticks, 4))
        ok2 = self.sync_write_goal.addParam(self.cfg.tilt.servo_id, int_to_little_endian_bytes(tilt_ticks, 4))
        if not (ok1 and ok2):
            raise RuntimeError("Failed to add params to sync write")

        dxl_comm_result = self.sync_write_goal.txPacket()
        if dxl_comm_result != 0:
            msg = self.packet_handler.getTxRxResult(dxl_comm_result)
            raise RuntimeError(f"sync_write_goal COMM FAIL: {msg}")

    def center(self) -> None:
        self.set_pan_tilt_deg(self.cfg.pan.home_deg, self.cfg.tilt.home_deg)

    def read_present_positions(self) -> dict:
        dxl_comm_result = self.sync_read_present.txRxPacket()
        if dxl_comm_result != 0:
            msg = self.packet_handler.getTxRxResult(dxl_comm_result)
            raise RuntimeError(f"sync_read_present COMM FAIL: {msg}")

        out = {}
        for s in (self.cfg.pan, self.cfg.tilt):
            if not self.sync_read_present.isAvailable(s.servo_id, ADDR_PRESENT_POSITION, LEN_PRESENT_POSITION):
                raise RuntimeError(f"Present position not available for servo {s.servo_id}")
            pos = self.sync_read_present.getData(s.servo_id, ADDR_PRESENT_POSITION, LEN_PRESENT_POSITION)
            out[s.name] = int(pos)
        return out


# -----------------------------
# CLI routines
# -----------------------------
def cmd_status(ctrl: DynamixelTurret) -> None:
    pos = ctrl.read_present_positions()
    pan_deg = ctrl.ticks_to_deg_physical(pos["pan"])
    tilt_deg = ctrl.ticks_to_deg_physical(pos["tilt"])
    print(f"PAN:  ticks={pos['pan']:4d}  physical_deg={pan_deg:7.2f}")
    print(f"TILT: ticks={pos['tilt']:4d}  physical_deg={tilt_deg:7.2f}")


def cmd_goto(ctrl: DynamixelTurret, pan: float, tilt: float, settle: float) -> None:
    ctrl.set_pan_tilt_deg(pan, tilt)
    time.sleep(settle)
    cmd_status(ctrl)


def cmd_step(ctrl: DynamixelTurret, axis: str, step_deg: float, n: int, settle: float) -> None:
    # Step around home
    pan = ctrl.cfg.pan.home_deg
    tilt = ctrl.cfg.tilt.home_deg

    for i in range(n):
        sign = 1 if (i % 2 == 0) else -1
        if axis == "pan":
            cmd_goto(ctrl, pan + sign * step_deg, tilt, settle)
        else:
            cmd_goto(ctrl, pan, tilt + sign * step_deg, settle)


def cmd_sweep(ctrl: DynamixelTurret, axis: str, step_deg: float, settle: float) -> None:
    if axis == "pan":
        s = ctrl.cfg.pan
        fixed = ctrl.cfg.tilt.home_deg
        d = s.min_deg
        while d <= s.max_deg + 1e-6:
            ctrl.set_pan_tilt_deg(d, fixed)
            time.sleep(settle)
            d += step_deg
    else:
        s = ctrl.cfg.tilt
        fixed = ctrl.cfg.pan.home_deg
        d = s.min_deg
        while d <= s.max_deg + 1e-6:
            ctrl.set_pan_tilt_deg(fixed, d)
            time.sleep(settle)
            d += step_deg
    cmd_status(ctrl)


def build_argparser() -> argparse.ArgumentParser:
    p = argparse.ArgumentParser(description="Dynamixel XL430 pan/tilt controller (U2D2 TTL).")
    p.add_argument("--port", default=TurretConfig.port, help="Serial port (e.g., /dev/ttyUSB0)")
    p.add_argument("--baud", type=int, default=TurretConfig.baud, help="Baudrate (e.g., 57600, 1000000)")
    p.add_argument("--pan_id", type=int, default=TurretConfig.pan.servo_id, help="Pan servo ID")
    p.add_argument("--tilt_id", type=int, default=TurretConfig.tilt.servo_id, help="Tilt servo ID")
    p.add_argument("--profile_velocity", type=int, default=TurretConfig.profile_velocity, help="Profile velocity (both)")
    p.add_argument("--max_step", type=float, default=TurretConfig.max_step_deg_per_cmd, help="Max deg change per command")

    sub = p.add_subparsers(dest="cmd", required=True)

    sub.add_parser("ping", help="Ping both servos and print model numbers")
    sub.add_parser("center", help="Move to home positions")
    sub.add_parser("status", help="Read present positions and print")

    g = sub.add_parser("goto", help="Move to pan/tilt degrees (logical)")
    g.add_argument("--pan", type=float, required=True)
    g.add_argument("--tilt", type=float, required=True)
    g.add_argument("--settle", type=float, default=0.5)

    st = sub.add_parser("step", help="Step test around home on one axis")
    st.add_argument("--axis", choices=["pan", "tilt"], required=True)
    st.add_argument("--step_deg", type=float, default=5.0)
    st.add_argument("--n", type=int, default=6)
    st.add_argument("--settle", type=float, default=0.5)

    sw = sub.add_parser("sweep", help="Sweep one axis through its soft limits")
    sw.add_argument("--axis", choices=["pan", "tilt"], required=True)
    sw.add_argument("--step_deg", type=float, default=5.0)
    sw.add_argument("--settle", type=float, default=0.4)

    return p


def main() -> int:
    args = build_argparser().parse_args()

    cfg = TurretConfig()
    cfg.port = args.port
    cfg.baud = args.baud
    cfg.profile_velocity = args.profile_velocity
    cfg.max_step_deg_per_cmd = args.max_step

    cfg.pan.servo_id = args.pan_id
    cfg.tilt.servo_id = args.tilt_id

    ctrl = DynamixelTurret(cfg)

    def _sigint_handler(sig, frame):
        print("\n[CTRL+C] Disabling torque and exiting...")
        try:
            ctrl.torque_off_all()
        finally:
            try:
                ctrl.port_handler.closePort()
            except Exception:
                pass
        sys.exit(130)

    signal.signal(signal.SIGINT, _sigint_handler)

    ctrl.open()

    # Basic setup
    ctrl.ping()
    ctrl.set_position_mode_all()
    ctrl.set_profile_velocity_all(cfg.profile_velocity)
    ctrl.torque_on_all()

    if args.cmd == "ping":
        pass
    elif args.cmd == "center":
        ctrl.center()
        time.sleep(0.7)
        cmd_status(ctrl)
    elif args.cmd == "status":
        cmd_status(ctrl)
    elif args.cmd == "goto":
        cmd_goto(ctrl, args.pan, args.tilt, args.settle)
    elif args.cmd == "step":
        cmd_step(ctrl, args.axis, args.step_deg, args.n, args.settle)
    elif args.cmd == "sweep":
        cmd_sweep(ctrl, args.axis, args.step_deg, args.settle)
    else:
        raise RuntimeError("Unknown command")

    ctrl.torque_off_all()
    ctrl.port_handler.closePort()
    return 0


if __name__ == "__main__":
    raise SystemExit(main())

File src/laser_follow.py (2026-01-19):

#!/usr/bin/env python3
"""
Laser follow (red dot) -> Dynamixel pan/tilt

Requires:
  pip install opencv-python dynamixel-sdk numpy

Run example:
  python3 laser_follow.py --port /dev/ttyUSB0 --baud 1000000 --cam 0 --width 1920 --height 1200 --v_thresh 80 --s_thresh 60 --deadband_px 10 --lost_frames_hold 1 --max_step_deg 3.0 --pan_dir -1

Controls:
  q / ESC  : quit (torque off)
"""

import argparse
import signal
import sys
import time
from dataclasses import dataclass

import cv2
import numpy as np
from dynamixel_sdk import PortHandler, PacketHandler, GroupSyncWrite, GroupSyncRead  # type: ignore


# -----------------------------
# Dynamixel XL430 Control Table (Protocol 2.0)
# -----------------------------
ADDR_OPERATING_MODE   = 11
ADDR_TORQUE_ENABLE    = 64
ADDR_PROFILE_VELOCITY = 112
ADDR_GOAL_POSITION    = 116
ADDR_PRESENT_POSITION = 132

LEN_GOAL_POSITION     = 4
LEN_PRESENT_POSITION  = 4

OPERATING_MODE_POSITION = 3
TORQUE_ON, TORQUE_OFF = 1, 0

TICKS_PER_REV = 4096.0
DEG_PER_TICK = 360.0 / TICKS_PER_REV


# -----------------------------
# Config
# -----------------------------
@dataclass
class ServoConfig:
    servo_id: int
    name: str
    min_deg: float
    max_deg: float
    home_deg: float
    invert: bool = False
    offset_deg: float = 0.0


@dataclass
class TurretConfig:
    port: str = "/dev/ttyUSB0"
    baud: int = 1000000
    protocol: float = 2.0
    profile_velocity: int = 200

    # Safety: how far a single update is allowed to change angle
    max_step_deg_per_update: float = 2.0

    pan: ServoConfig = ServoConfig(
        servo_id=1, name="pan",
        min_deg=0.0, max_deg=360.0,
        home_deg=180.0,
        invert=False, offset_deg=0.0
    )
    tilt: ServoConfig = ServoConfig(
        servo_id=2, name="tilt",
        min_deg=62.23, max_deg=191.78,
        home_deg=120.0,
        invert=False, offset_deg=0.0
    )


def clamp(x: float, lo: float, hi: float) -> float:
    return max(lo, min(hi, x))


def wrap_deg_0_360(deg: float) -> float:
    d = deg % 360.0
    if d < 0:
        d += 360.0
    return d


def int_to_le_bytes(value: int, length: int) -> bytes:
    return int(value).to_bytes(length, byteorder="little", signed=False)


# -----------------------------
# Red laser detection (HSV)
# -----------------------------
def find_laser_centroid_red(frame_bgr,
                            v_thresh=80,
                            s_thresh=40,
                            min_area=1,
                            max_area=2000):
    """
    Red-laser dot detection:
    - HSV threshold for red (two hue ranges)
    - Allows low saturation (important at distance on walls)
    """
    hsv = cv2.cvtColor(frame_bgr, cv2.COLOR_BGR2HSV)
    h, s, v = cv2.split(hsv)

    lower1 = np.array([0,   s_thresh, v_thresh], dtype=np.uint8)
    upper1 = np.array([10,  255,      255],      dtype=np.uint8)
    lower2 = np.array([170, s_thresh, v_thresh], dtype=np.uint8)
    upper2 = np.array([179, 255,      255],      dtype=np.uint8)

    mask = cv2.bitwise_or(cv2.inRange(hsv, lower1, upper1),
                          cv2.inRange(hsv, lower2, upper2))

    kernel = np.ones((3, 3), np.uint8)
    mask = cv2.morphologyEx(mask, cv2.MORPH_OPEN, kernel, iterations=1)
    mask = cv2.dilate(mask, kernel, iterations=2)

    contours, _ = cv2.findContours(mask, cv2.RETR_EXTERNAL, cv2.CHAIN_APPROX_SIMPLE)
    if not contours:
        return None, mask

    best = None
    best_score = -1.0
    for c in contours:
        area = cv2.contourArea(c)
        if area < min_area or area > max_area:
            continue
        x, y, w, h2 = cv2.boundingRect(c)
        roi_v = v[y:y+h2, x:x+w]
        mean_v = float(np.mean(roi_v)) if roi_v.size else 0.0
        score = mean_v - 0.03 * area
        if score > best_score:
            best_score = score
            best = c

    if best is None:
        return None, mask
        
    # Confidence gate: require a very bright core inside the detected blob
    x, y, w, h2 = cv2.boundingRect(best)
    roi_v = v[y:y+h2, x:x+w]
    peak_v = int(np.max(roi_v)) if roi_v.size else 0
    
    area = cv2.contourArea(best)
    
    if peak_v < 215:   # tune: +30 to +80
        return None, mask
    if area < 2 or area > 300:
    	return None, mask

    M = cv2.moments(best)
    if M["m00"] == 0:
        return None, mask
    cx = int(M["m10"] / M["m00"])
    cy = int(M["m01"] / M["m00"])
    return (cx, cy), mask


# -----------------------------
# Dynamixel turret control
# -----------------------------
class DynamixelTurret:
    def __init__(self, cfg: TurretConfig):
        self.cfg = cfg
        self.port_handler = PortHandler(cfg.port)
        self.packet_handler = PacketHandler(cfg.protocol)

        self.sync_write_goal = GroupSyncWrite(
            self.port_handler, self.packet_handler, ADDR_GOAL_POSITION, LEN_GOAL_POSITION
        )
        self.sync_read_present = GroupSyncRead(
            self.port_handler, self.packet_handler, ADDR_PRESENT_POSITION, LEN_PRESENT_POSITION
        )

        self.pan_cmd = cfg.pan.home_deg
        self.tilt_cmd = cfg.tilt.home_deg

    def _check(self, servo_id: int, comm: int, err: int, what: str):
        if comm != 0:
            raise RuntimeError(f"[ID:{servo_id}] {what} COMM FAIL: {self.packet_handler.getTxRxResult(comm)}")
        if err != 0:
            raise RuntimeError(f"[ID:{servo_id}] {what} DXL ERROR: {self.packet_handler.getRxPacketError(err)}")

    def open(self):
        if not self.port_handler.openPort():
            raise RuntimeError(f"Failed to open port {self.cfg.port}")
        if not self.port_handler.setBaudRate(self.cfg.baud):
            raise RuntimeError(f"Failed to set baudrate {self.cfg.baud} on {self.cfg.port}")

        for s in (self.cfg.pan, self.cfg.tilt):
            if not self.sync_read_present.addParam(s.servo_id):
                raise RuntimeError(f"Failed to add servo {s.servo_id} to sync read")

    def close(self):
        try:
            self.torque_off()
        except Exception:
            pass
        try:
            self.port_handler.closePort()
        except Exception:
            pass

    def ping(self):
        for s in (self.cfg.pan, self.cfg.tilt):
            model, comm, err = self.packet_handler.ping(self.port_handler, s.servo_id)
            self._check(s.servo_id, comm, err, "ping")
            print(f"[OK] {s.name} ID={s.servo_id} model_number={model}")

    def write1(self, servo_id: int, addr: int, value: int):
        comm, err = self.packet_handler.write1ByteTxRx(self.port_handler, servo_id, addr, value)
        self._check(servo_id, comm, err, f"write1 addr={addr}")

    def write4(self, servo_id: int, addr: int, value: int):
        comm, err = self.packet_handler.write4ByteTxRx(self.port_handler, servo_id, addr, value)
        self._check(servo_id, comm, err, f"write4 addr={addr}")
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

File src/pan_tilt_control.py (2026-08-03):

"""Qt-free Dynamixel pan/tilt hardware and fixed-rate tracking control."""

import threading
import time
from dataclasses import dataclass
from typing import Optional, Protocol, Tuple

from dynamixel_sdk import (  # type: ignore
    GroupSyncRead,
    GroupSyncWrite,
    PacketHandler,
    PortHandler,
)

from tracking_core import (
    ControlTarget,
    FilteredDerivative,
    clamp,
    degrees_to_position_ticks,
    position_ticks_to_degrees,
    sanitize_motion_profile,
    tracking_pd_delta_degrees,
)


# XL430 Control Table (Protocol 2.0)
ADDR_OPERATING_MODE = 11
ADDR_MAX_POSITION_LIMIT = 48
ADDR_MIN_POSITION_LIMIT = 52
ADDR_TORQUE_ENABLE = 64
ADDR_HARDWARE_ERROR_STATUS = 70
ADDR_BUS_WATCHDOG = 98
ADDR_PROFILE_ACCELERATION = 108
ADDR_PROFILE_VELOCITY = 112
ADDR_GOAL_POSITION = 116
ADDR_PRESENT_LOAD = 126
ADDR_PRESENT_VELOCITY = 128
ADDR_PRESENT_POSITION = 132
ADDR_PRESENT_INPUT_VOLTAGE = 144
ADDR_PRESENT_TEMPERATURE = 146

# XL430 Hardware Error Status(70): voltage, temperature, encoder, electrical
# shock/insufficient power, and overload. Bits 1, 6, and 7 are reserved and
# must always be zero.
HARDWARE_ERROR_VALID_MASK = 0x3D

LEN_GOAL_POSITION = 4
LEN_PRESENT_STATE = 8
LEN_PRESENT_HEALTH = 21

OPERATING_MODE_POSITION = 3
TORQUE_ON, TORQUE_OFF = 1, 0

DXL_VELOCITY_UNIT_DEG_S = 0.229 * 6.0
BUS_WATCHDOG_TICKS = 25  # 25 * 20 ms = 500 ms
APPLICATION_TILT_MIN_TICKS = 708  # Temporary 62.23-degree mechanical guard.
SYNC_READ_ATTEMPTS = 2
STATUS_READ_ATTEMPTS = 3
STATUS_READ_RETRY_DELAY_SEC = 0.002


class DynamixelCommunicationError(RuntimeError):
    """Transient transport/status-packet failure on the Dynamixel bus."""


class DynamixelHardwareError(RuntimeError):
    """Latched device-reported hardware fault that must not auto-rearm."""


class ControlParams(Protocol):
    rate_hz: float
    profile_velocity: int
    profile_acceleration: int
    tracking_enabled: bool
    servos_enabled: bool
    deadband_px: int
    deg_per_px_pan: float
    deg_per_px_tilt: float
    pan_damping_gain: float
    tilt_damping_gain: float
    pan_dir: int
    tilt_dir: int
    max_step_deg: float


class ParamProvider(Protocol):
    def get(self) -> ControlParams:
        ...


def int_to_le_bytes(value: int, length: int) -> bytes:
    return int(value).to_bytes(length, byteorder="little", signed=False)


@dataclass(frozen=True)
class ServoHealth:
    load_percent: float = 0.0
    input_voltage: float = 0.0
    temperature_c: int = 0
    hardware_error: int = 0


class DynamixelPanTilt:
    """Low-level XL430 interface; callers must serialize all bus access."""

    def __init__(self, port: str, baud: int, pan_id: int, tilt_id: int):
        self.port = port
        self.baud = baud
        self.pan_id = pan_id
        self.tilt_id = tilt_id

        self.protocol = 2.0
        self.port_handler = PortHandler(self.port)
        self.packet_handler = PacketHandler(self.protocol)
        self.sync_write_goal = GroupSyncWrite(
            self.port_handler,
            self.packet_handler,
            ADDR_GOAL_POSITION,
            LEN_GOAL_POSITION,
        )
        self.sync_read_state = GroupSyncRead(
            self.port_handler,
            self.packet_handler,
            ADDR_PRESENT_VELOCITY,
            LEN_PRESENT_STATE,
        )
        self.sync_read_health = GroupSyncRead(
            self.port_handler,
            self.packet_handler,
            ADDR_PRESENT_LOAD,
            LEN_PRESENT_HEALTH,
        )
        if not self.sync_read_state.addParam(self.pan_id):
            raise RuntimeError(f"Failed to add pan ID {self.pan_id} to sync read")
        if not self.sync_read_state.addParam(self.tilt_id):
            raise RuntimeError(f"Failed to add tilt ID {self.tilt_id} to sync read")
        if not self.sync_read_health.addParam(self.pan_id):
            raise RuntimeError(f"Failed to add pan ID {self.pan_id} to health read")
        if not self.sync_read_health.addParam(self.tilt_id):
            raise RuntimeError(f"Failed to add tilt ID {self.tilt_id} to health read")

        # Populated from the control table after open(). Dynamixel Wizard is
        # authoritative; this application does not duplicate its limits.
        self.position_limits_ticks = {
            self.pan_id: (0, 4095),
            self.tilt_id: (0, 4095),
        }
        self.configured_position_limits_ticks = dict(self.position_limits_ticks)
        self.pan_min, self.pan_max = 0.0, 360.0
        self.tilt_min, self.tilt_max = 0.0, 360.0
        self.pan_cmd = 0.0
        self.tilt_cmd = 0.0
        self.pan_actual = 0.0
        self.tilt_actual = 0.0
        self.pan_velocity = 0.0
        self.tilt_velocity = 0.0
        self.pan_health = ServoHealth()
        self.tilt_health = ServoHealth()

        self.opened = False
        self.torque = False
        self.motion_profile = None

    def _check(self, servo_id: int, comm: int, err: int, what: str) -> None:
        if comm != 0:
            raise DynamixelCommunicationError(
                f"[ID:{servo_id}] {what} COMM FAIL: "
                f"{self.packet_handler.getTxRxResult(comm)}"
            )
        if err != 0:
            raise RuntimeError(
                f"[ID:{servo_id}] {what} DXL ERROR: "
                f"{self.packet_handler.getRxPacketError(err)}"
            )

    def open(self) -> None:
        if self.opened:
            return
        if not self.port_handler.openPort():
            raise RuntimeError(f"Failed to open port {self.port}")
        if not self.port_handler.setBaudRate(self.baud):
            self.port_handler.closePort()
            raise RuntimeError(f"Failed to set baudrate {self.baud}")
        self.opened = True
        try:
            # Setting the mode resets the motion profile; the controller
            # reapplies it immediately before torque is enabled.
            self.torque_off(best_effort=False)
            for servo_id in (self.pan_id, self.tilt_id):
                comm, err = self.packet_handler.write1ByteTxRx(
                    self.port_handler,
                    servo_id,
                    ADDR_OPERATING_MODE,
                    OPERATING_MODE_POSITION,
                )
                self._check(servo_id, comm, err, "set operating mode")
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

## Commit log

2025-07-07 first bracket printed
    quality of the first printed bracket before any modifications where made
2026-01-04 Add files via upload
    STL files for the Tilt Mount.
    [tilt mount V2.STL, tilt mount V3.STL, tilt mount V4.STL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]
2026-01-05 Revise Update5JAN26 with printing and component notes
    Updated log with details on turret mount printing and component acquisition.
2026-01-19 added python code and stereovision calibration
2026-01-19 added weekly update as well as changing speed values for servo's in laser_follow.py
2026-02-23 Refactor comments for clarity in laser_follow_gui.py
2026-08-02 Build fixed-rate pan tilt controller
    [laser_follow_gui.py, pan_tilt_control.py, test_pan_tilt_control.py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]
2026-08-03 Restore usable automatic camera exposure
2026-08-03 Accelerate Jetson camera conversion
2026-08-03 Fix accelerated camera caps negotiation
    [camera_pipeline.py, laser_follow_gui.py, test_camera_pipeline.py]
2026-08-03 Preserve tiny laser dot candidates
2026-08-03 Reject laser targets at image edges
2026-08-03 Adapt laser detection to wall lighting
2026-08-03 Recover safe servo diagnostics
2026-08-03 Stabilize tracking and preserve target identity
    [dashboard_core.py, laser_follow_gui.py, test_dashboard_core.py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]
2026-08-03 Retry transient Dynamixel status failures
    [pan_tilt_control.py, test_pan_tilt_control.py]
2026-08-03 Add filtered pan and tilt damping
2026-08-03 Validate servo telemetry and reduce bus polling
